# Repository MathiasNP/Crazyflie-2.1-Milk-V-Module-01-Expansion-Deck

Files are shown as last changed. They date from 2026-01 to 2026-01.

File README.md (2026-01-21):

# BT-MV Duo 01 Deck
*A Crazyflie 2.1 expansion deck that brings a Milk-V Duo Module 01 into the nano-UAV world — with hooks for SD/MMC, USB, and a camera.*

> **Status (Rev-A):** boots over UART and power is solid.  
> **Blockers:** SD/MMC and USB are not working yet, which prevents full end-to-end camera validation.

---

## What this project is
This repository contains the hardware design for a Crazyflie 2.1 deck integrating a Milk-V Duo Module 01 (dual-core SoM) to enable on-board compute beyond the stock platform. The aim is a lightweight, compact board that can be manufactured, assembled, and iterated on like any other Crazyflie expansion deck.

---

## Highlights
- Crazyflie deck form factor (mechanically compatible)
- Milk-V Duo Module 01 integration
- Power path designed for both Crazyflie supply (VCOM) and external USB 5 V (VBUS) with automatic switchover
- Interfaces on the board (intended): microSD (SD/MMC), USB 2.0, OV5647-style camera connector, UART debug

---

## What works (verified on Rev-A)
### ✅ Power & regulation
- 3.3 V rail is stable across expected input conditions
- VBUS/VCOM switchover behaves as intended (no brown-out observed during switching)

### ✅ Boot & console
- RISC-V boot path reachable via UART
- U-Boot prompt available and interactive

---

## What does *not* work yet (known issues)
### ❌ SD/MMC (microSD)
Symptoms:
- SDHCI initialisation repeatedly times out
- Environment load from FAT fails; boot falls back to defaults

Most likely causes (current hypotheses):
- Signal integrity / timing margin issues on CMD/CLK/DAT lines
- Protection / filtering choice on the SD bus introducing too much series impedance

### ❌ USB (device not recognised)
Symptoms:
- VBUS present (board powers), but host does not enumerate the device
- Removing protection components on D+/D− did not resolve enumeration

Most likely causes (current hypotheses):
- Attach signalling / CC configuration (if USB-C path is involved)
- D+/D− routing/impedance/return path issues

### ⚠️ Camera
- Camera rails exist and basic clock presence was observed on Rev-A,
  but full camera bring-up is blocked until a reliable flashing / data path exists
  (SD and/or USB need to work first).

---

## Repository structure
```text
BT-MV Duo 01 Deck/
  BT-MV Duo 01 Deck.kicad_pcb            # PCB layout
  BT-MV Duo 01 Deck.kicad_prl            # Local project settings
  BT-MV Duo 01 Deck.kicad_pro            # KiCad project file

  MV Duo 01 Deck Schematics/             # Hierarchical schematics
    BT-MV Duo 01 Deck.kicad_sch          # Top-level schematic
    BT-Power_CFexp.kicad_sch             # Power + Crazyflie expansion interface
    BT-SDcard.kicad_sch                  # microSD (SD/MMC)
    BT-USB_UART.kicad_sch                # USB + UART debug
    BT-CameraOV.kicad_sch                # Camera connector + signals
    BT-MV_DM01.kicad_sch                 # Duo Module integration (pins/straps)
    BT-Others.kicad_sch                  # LEDs, buttons, misc

  BT-MVD01 libraries/                    # Custom KiCad libraries
    Symbols and Footprints/
    3D Models/
    BT-Milk V Duo S.pretty/              # Footprint library

  BT-MV Duo 01 Deck.csv                  # BOM
  BT-MV Duo 01 Deck.kicad_dru            # Design rules

  Related Work/
    CF Proto Exp/                        # Bitcraze deck template/docs
    Milk Module schematics/              # Module + EVB references
    Camera OV5674/                       # Camera reference material (may include mixed sensor notes)

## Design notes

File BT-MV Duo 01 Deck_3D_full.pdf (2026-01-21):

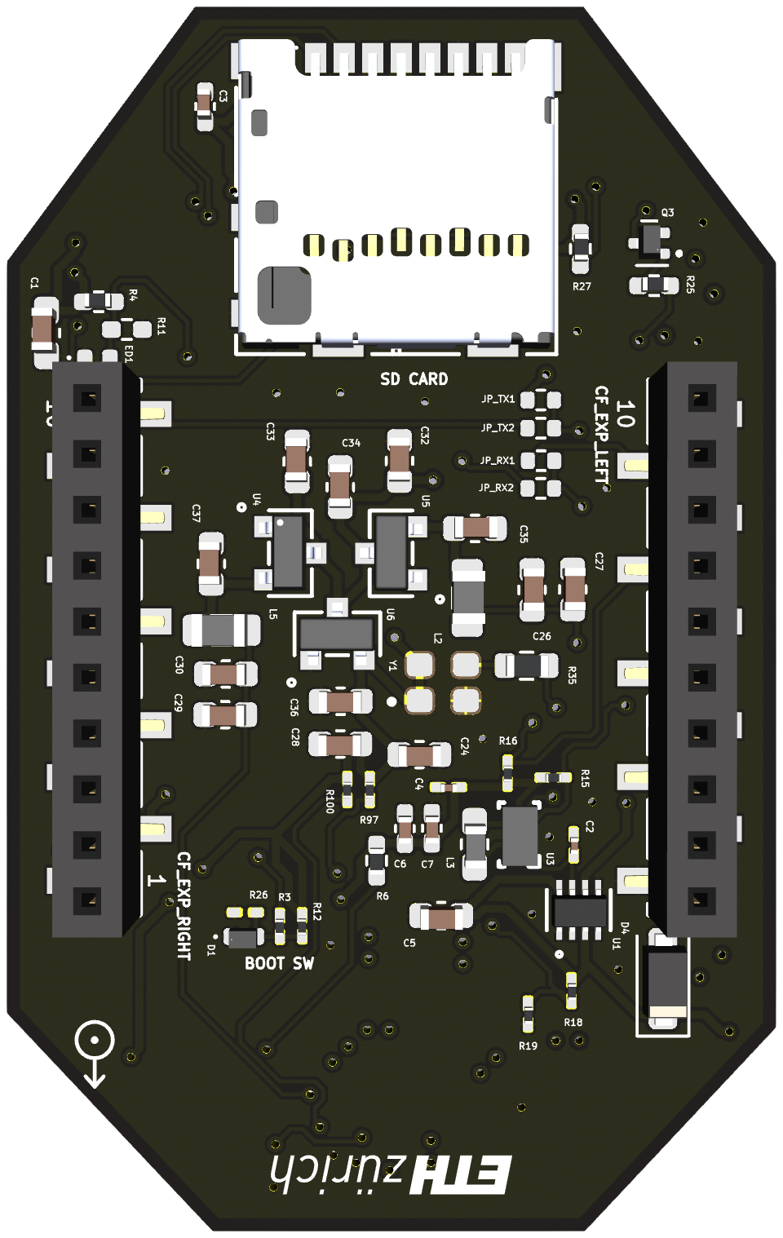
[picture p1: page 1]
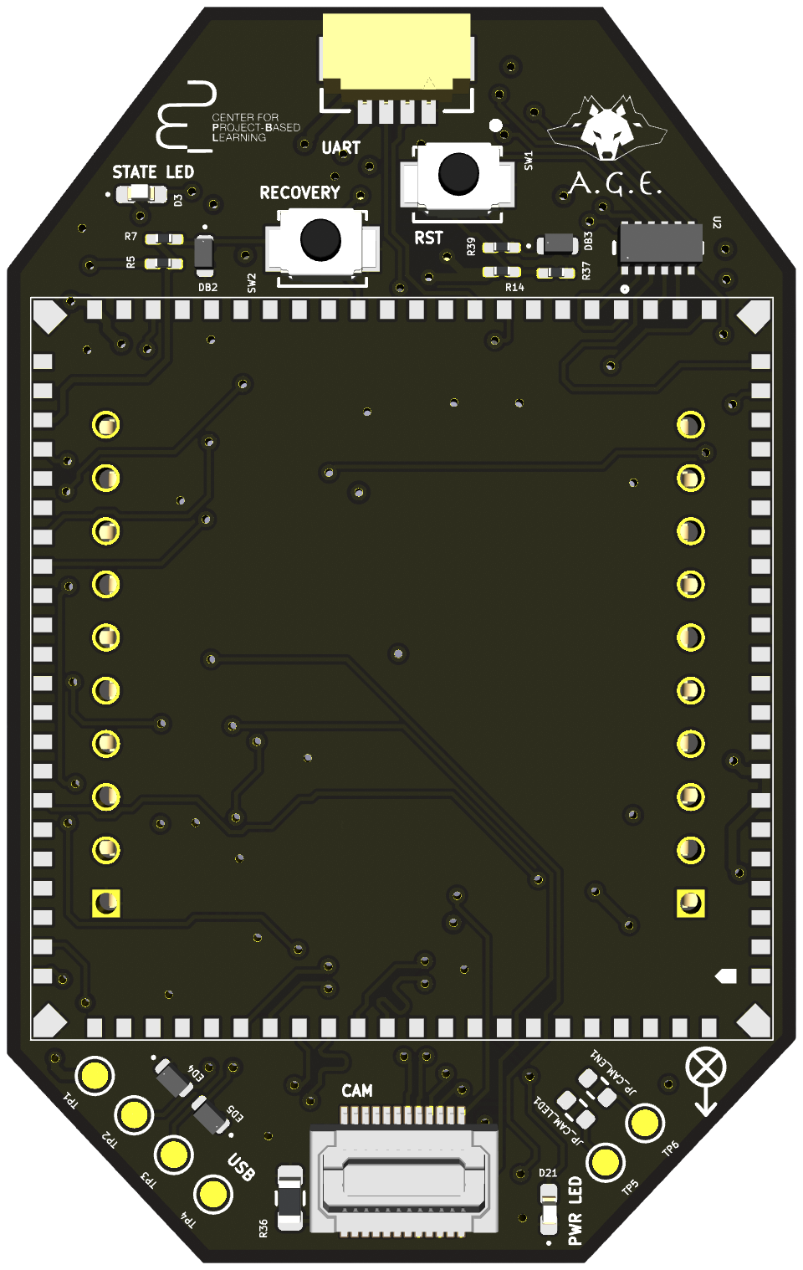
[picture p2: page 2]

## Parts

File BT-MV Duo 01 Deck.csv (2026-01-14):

Reference | Qty | Value | DNP | Exclude from BOM | Exclude from Board | Footprint | Datasheet
C1 | 1 | 10uF |  |  |  | Capacitor_SMD:C_0603_1608Metric_Pad1.08x0.95mm_HandSolder | CM05X5R106M10AH
C2 | 1 | 10uF |  |  |  | Capacitor_SMD:C_0201_0603Metric_Pad0.64x0.40mm_HandSolder | CM05X5R106M10AH
C3 | 1 | 100nF |  |  |  | Capacitor_SMD:C_0402_1005Metric_Pad0.74x0.62mm_HandSolder | GRM155R61A104KA01J
C4 | 1 | 100nF |  |  |  | Capacitor_SMD:C_0201_0603Metric_Pad0.64x0.40mm_HandSolder | GRM033R61A104ME15D
C5,C32,C33,C34,C35,C36,C37 | 7 | 1uF |  |  |  | Capacitor_SMD:C_0603_1608Metric | CL10A105KA8NNNC
C6,C7 | 2 | 22uF |  |  |  | Capacitor_SMD:C_0402_1005Metric_Pad0.74x0.62mm_HandSolder | GRM155R60J226ME11D
C24,C27,C28,C30 | 4 | 10nF |  |  |  | Capacitor_SMD:C_0603_1608Metric | GCM188R71H103KA37J
C26,C29 | 2 | 1nF |  |  |  | Capacitor_SMD:C_0603_1608Metric | CC0603KRX7R9BB102
D1,DB2,DB3,ED1,ED4,ED5 | 6 | SP0402B-ULC-01ETG |  |  |  | Diode_SMD:D_0402_1005Metric | SP0402B-ULC-01ETG
D3 | 1 | BLUE HIGH D402 |  |  |  | LED_SMD:LED_0402_1005Metric_Pad0.77x0.64mm_HandSolder | 150040BS73240
D4 | 1 | SMBJ18A |  |  |  | Diode_SMD:D_SOD-123F | SMBJ18A
D21 | 1 | RED HIGH D402 |  |  |  | LED_SMD:LED_0402_1005Metric_Pad0.77x0.64mm_HandSolder | 150040RS73240
J1 | 1 | 1040310811 |  |  |  | BT-Milk V Duo S:104031-0811_MOL | 104031-0811
J2 | 1 | STAMP_HOLE_88P |  |  |  | BT-Milk V Duo S:MilkV_Duo_Module | https://milkv.io/duo-module-01
J6 | 1 | DF52-4S-0.8H21 |  |  |  | BT-Milk V Duo S:CONN4X1_DF52-4S-0.8H21_HIR | https://www.mouser.ch/datasheet/3/731/1/DF52_2832PCF_CL0668_0030_5_00_Catalog_en_DF52_CAT.pdf
JP_CAM_EN1,JP_CAM_LED1,JP_RX1,JP_RX2,JP_TX1,JP_TX2 | 6 | 0R | DNP |  |  | Resistor_SMD:R_0402_1005Metric | RC0402JR-070RP
L2,L5 | 2 | 1.5k |  |  |  | Inductor_SMD:L_0805_2012Metric | BLM21BD152SH1D
L3 | 1 | 0.47uH |  |  |  | Inductor_SMD:L_0201_0603Metric_Pad0.64x0.40mm_HandSolder | LBCNF1608KKTR47MAD
P1 | 1 | CF_EXP_LEFT |  |  |  | BT-Milk V Duo S:CF2-DECK-SMD-HOLES | https://store.bitcraze.io/products/female-deck-connector?utm_source=chatgpt.com
P2 | 1 | CF_EXP_RIGHT |  |  |  | BT-Milk V Duo S:CF2-DECK-SMD-HOLES | https://store.bitcraze.io/products/female-deck-connector?utm_source=chatgpt.com
Q3 | 1 | CJ3134K |  |  |  | Package_TO_SOT_SMD:SOT-723 | CJ3134K / NTK3134NT1G
R3,R7,R39 | 3 | 100R 5% |  |  |  | Resistor_SMD:R_0201_0603Metric_Pad0.64x0.40mm_HandSolder | AC0201JR-07100RL
R4 | 1 | 100k(NC) |  |  |  | Resistor_SMD:R_0402_1005Metric_Pad0.72x0.64mm_HandSolder | RC0402FR-07100KL
R5,R12 | 2 | 10k 1% |  |  |  | Resistor_SMD:R_0201_0603Metric_Pad0.64x0.40mm_HandSolder | AC0201FR-0710KL
R6 | 1 | 510R 5% |  |  |  | Resistor_SMD:R_0402_1005Metric_Pad0.72x0.64mm_HandSolder | RC0402JR-07510RL
R11 | 1 | 100k(NC) | DNP |  |  | Resistor_SMD:R_0402_1005Metric_Pad0.72x0.64mm_HandSolder | RC0402FR-07100KL
R14,R15,R16,R97,R100 | 5 | 4.7k |  |  |  | Resistor_SMD:R_0201_0603Metric_Pad0.64x0.40mm_HandSolder | AC0201JR-074K7L
R18 | 1 | 150k |  |  |  | Resistor_SMD:R_0201_0603Metric_Pad0.64x0.40mm_HandSolder | AA0201FR-07150KL
R19 | 1 | 100k |  |  |  | Resistor_SMD:R_0201_0603Metric_Pad0.64x0.40mm_HandSolder | AA0201FR-07100KL
R25,R27 | 2 | 1k |  |  |  | Resistor_SMD:R_0402_1005Metric_Pad0.72x0.64mm_HandSolder | RC0402JR-071KL
R26 | 1 | 10k 1% | DNP |  |  | Resistor_SMD:R_0201_0603Metric_Pad0.64x0.40mm_HandSolder | AC0201FR-0710KL
R35 | 1 | 100R |  |  |  | Resistor_SMD:R_0603_1608Metric | RC0603FR-07100RL
R36 | 1 | 10k |  |  |  | Resistor_SMD:R_0603_1608Metric | RC0603FR-0710KL
R37 | 1 | 3.3k |  |  |  | Resistor_SMD:R_0201_0603Metric_Pad0.64x0.40mm_HandSolder | AC0201JR-073K3L
SW1,SW2 | 2 | B3U-1000P |  |  |  | Button_Switch_SMD:SW_SPST_B3U-1000P | B3U-1000P
TP1 | 1 | VBUS |  |  |  | TestPoint:TestPoint_Pad_D1.0mm | ~
TP2 | 1 | D- |  |  |  | TestPoint:TestPoint_Pad_D1.0mm | ~
TP3 | 1 | D+ |  |  |  | TestPoint:TestPoint_Pad_D1.0mm | ~
TP4 | 1 | GND |  |  |  | TestPoint:TestPoint_Pad_D1.0mm | ~
TP5,TP6 | 2 | TestPoint |  |  |  | TestPoint:TestPoint_Pad_D1.0mm | ~
U1 | 1 | LM66200DRLR |  |  |  | BT-Milk V Duo S:SOT-5X3_DRL_TEX | LM66200DRLR
U2 | 1 | EMIF06-1005MX12Y |  |  |  | BT-Milk V Duo S:SON_5MX12Y_STM | EMIF06-1005MX12Y
U3 | 1 | TPS63810YFFR |  |  |  | BT-Milk V Duo S:YFF0015AHAN | TPS63810YFFR
U4 | 1 | AP7313-15SRG-7 |  |  |  | BT-Milk V Duo S:SOT-23_DIO | AP7313-15SRG-7
U5 | 1 | AP2127N-2.8TRG1 |  |  |  | BT-Milk V Duo S:SOT-23_DIO | AP2127N-2.8TRG1
U6 | 1 | AP2127N-1.8TRG1 |  |  |  | BT-Milk V Duo S:SOT-23_DIO | AP2127N-1.8TRG1
U7 | 1 | DF30FC-24DS-0.4V(81) |  |  |  | BT-Milk V Duo S:DF30FC-24DS | DF30FC-24DS-0.4V(81)
Y1 | 1 | SG-210STF_25.0000MY |  |  |  | BT-Milk V Duo S:OSCCC250X200X90 | SG-210STF 25.0000MY

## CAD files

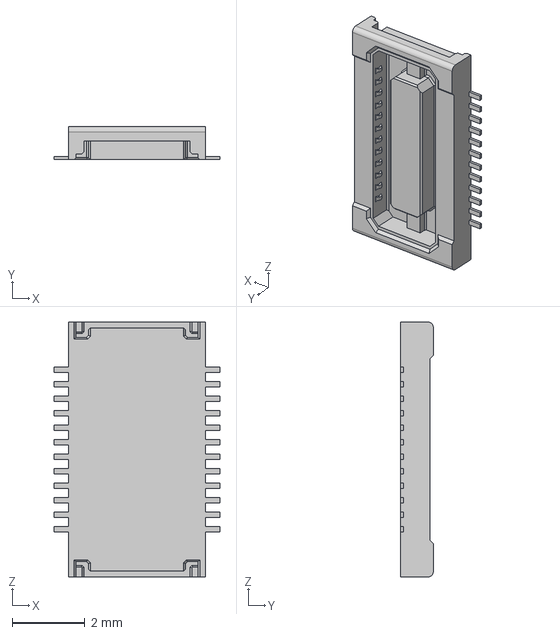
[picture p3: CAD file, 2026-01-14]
BT-MVD01 libraries/Symbols and Footprints/DF30FC-24DS-0.4V_82_/DF30FC-24DS-0.4V_82_.step
4.56 x 0.9 x 7.02 mm

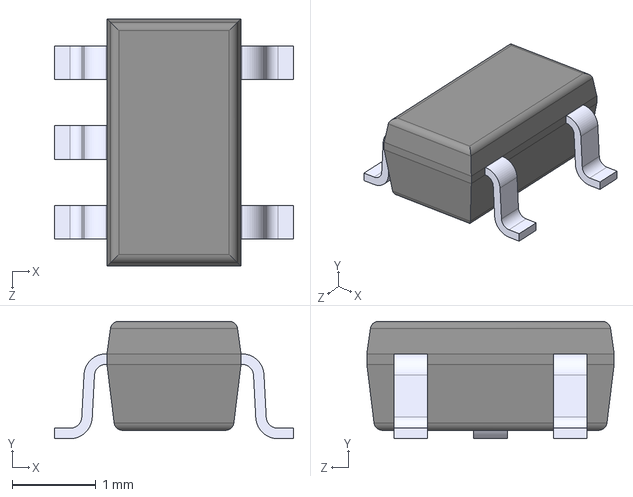
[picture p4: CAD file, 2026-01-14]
BT-MVD01 libraries/Symbols and Footprints/SY6280AAC/SY6280AAC.step
2.85 x 1.40 x 2.95 mm

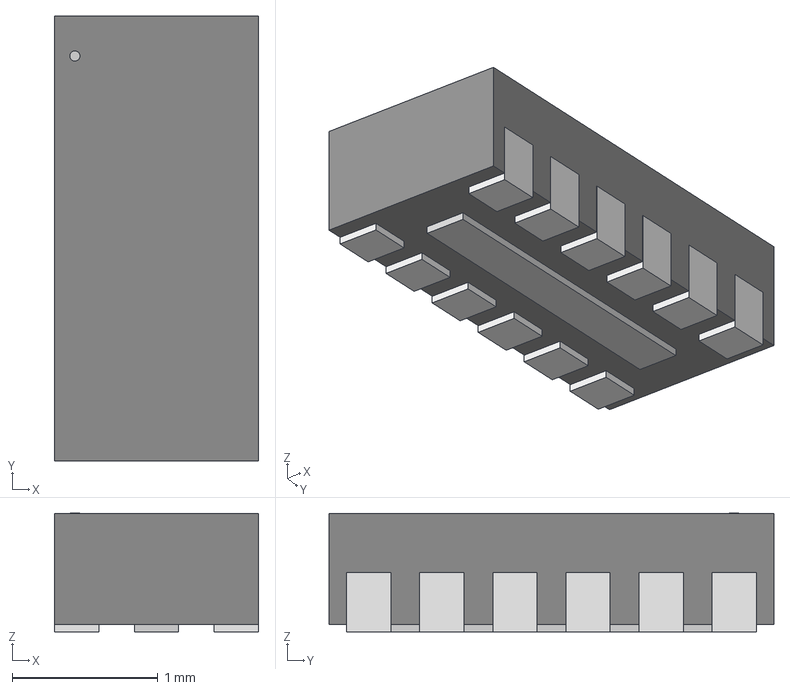
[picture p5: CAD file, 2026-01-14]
BT-MVD01 libraries/Symbols and Footprints/ul_EMIF06-1005MX12Y-2/SON_5MX12Y_STM.step
1.40 x 3.05 x 0.815 mm

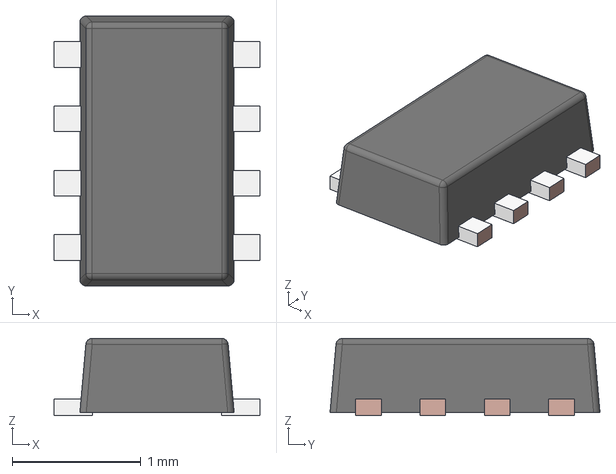
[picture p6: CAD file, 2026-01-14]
BT-MVD01 libraries/Symbols and Footprints/ul_LM66200DRLR-2/DRL0008A.stp
1.60 x 2.10 x 0.6 mm
FRAME-DRL0008A
BODY-SOT

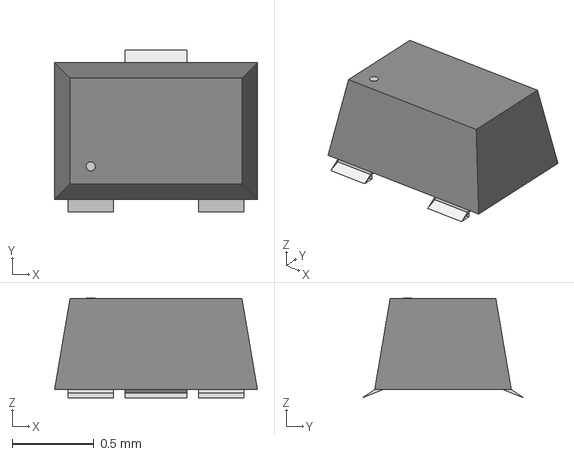
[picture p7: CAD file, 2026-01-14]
BT-MVD01 libraries/Symbols and Footprints/ul_NTK3134NT1G/SOT_34NT1G_ONS.step
1.24 x 0.99 x 0.612 mm

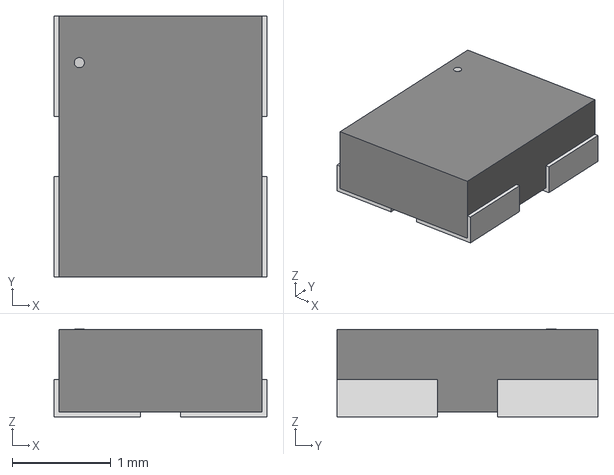
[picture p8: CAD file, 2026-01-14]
BT-MVD01 libraries/Symbols and Footprints/ul_SG-210STF-24-0000ML0/SG-210STF_EPS.step
2.16 x 2.64 x 0.892 mm

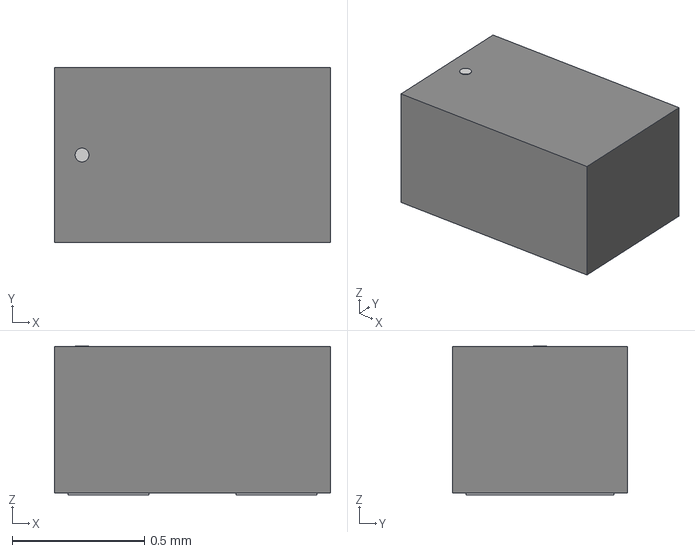
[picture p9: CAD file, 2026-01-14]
BT-MVD01 libraries/Symbols and Footprints/ul_SP0402B-ULC-01ETG/SP0402_LTF.step
1.04 x 0.66 x 0.561 mm

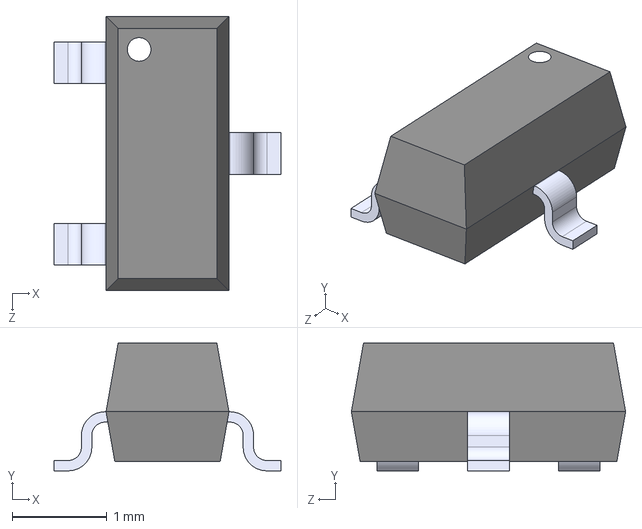
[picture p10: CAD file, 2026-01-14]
BT-MVD01 libraries/3D Models/AP7313-15SRG-7.STEP
2.40 x 1.35 x 2.90 mm

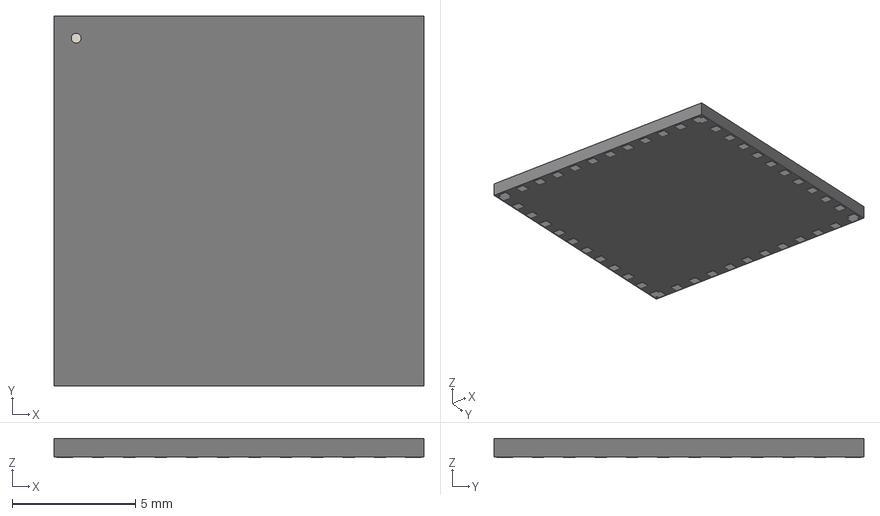
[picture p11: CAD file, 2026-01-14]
BT-MVD01 libraries/3D Models/Linear_LGA-133_15.0x15.0_Layout12x12_P1.27mm.step
15.0 x 15.0 x 0.78 mm

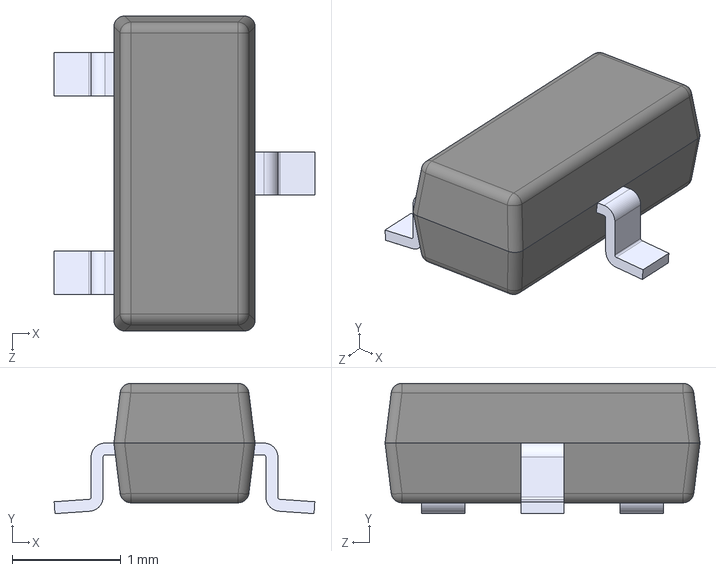
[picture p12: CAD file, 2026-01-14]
BT-MVD01 libraries/3D Models/AP2127N-2.8TRG1.STEP
2.40 x 1.20 x 2.90 mm

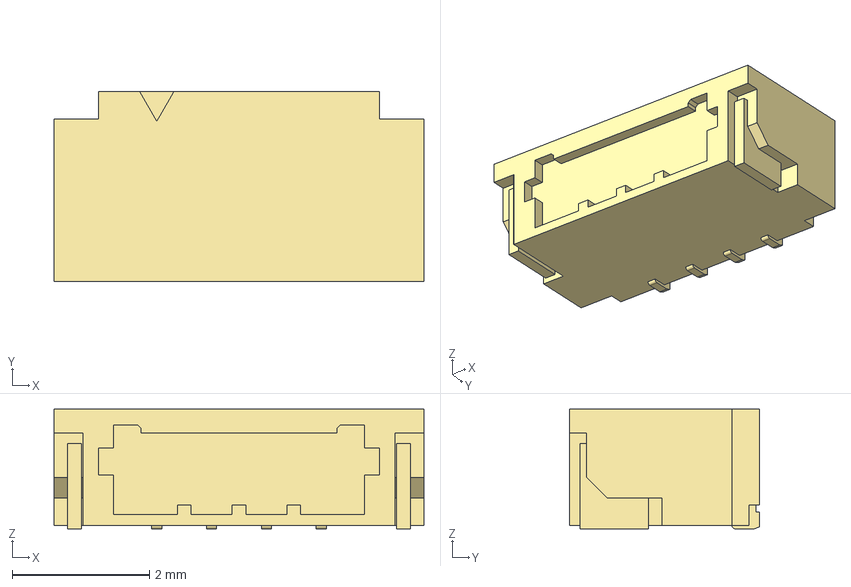
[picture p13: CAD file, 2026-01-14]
BT-MVD01 libraries/3D Models/DF52-4S-0.8H-21---3DModel-STEP-1.STEP
5.40 x 2.77 x 1.75 mm

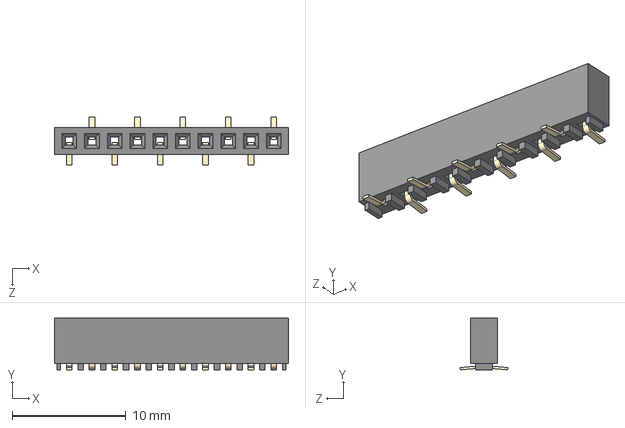
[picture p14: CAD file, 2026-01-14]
BT-MVD01 libraries/3D Models/BF090-10-A-1-N-D--3DModel-STEP-56544.STEP
20.6 x 4.55 x 4.20 mm
BF090-xxxx body_10
pin^BF090-xxxx x 5

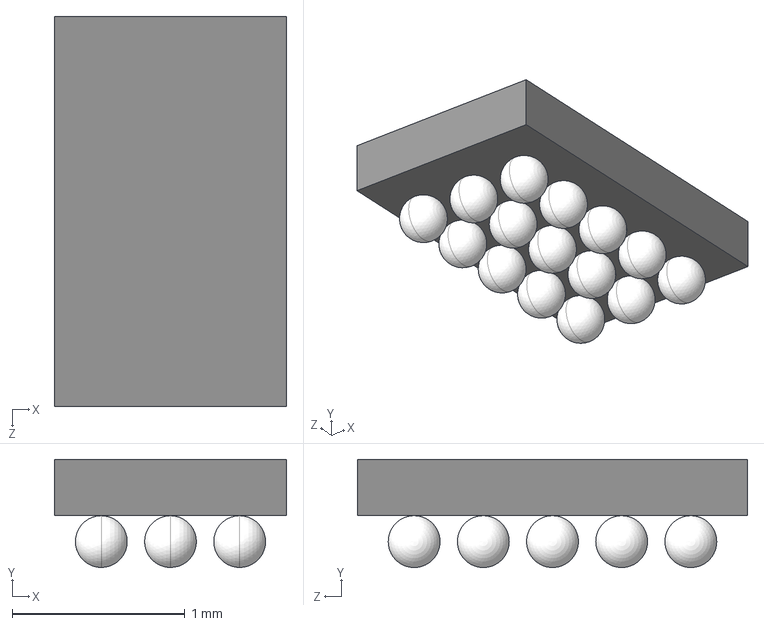
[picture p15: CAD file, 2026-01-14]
BT-MVD01 libraries/3D Models/TPS63805YFFR--3DModel-STEP-56544.STEP
1.34 x 0.625 x 2.25 mm

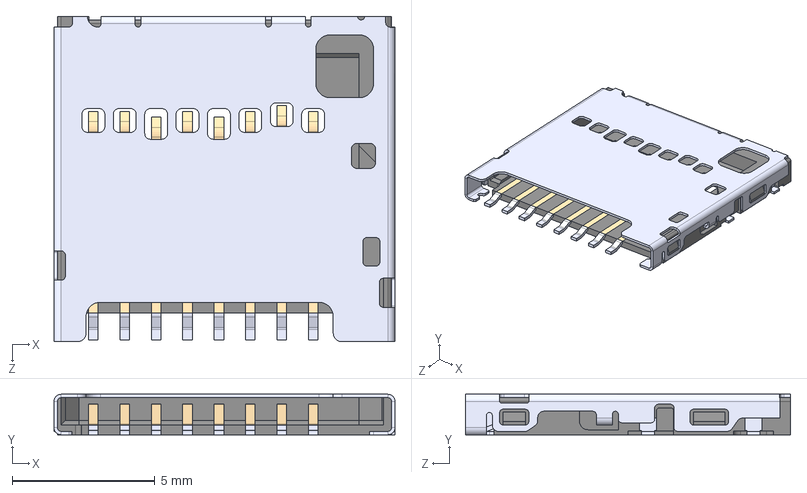
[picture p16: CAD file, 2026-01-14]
BT-MVD01 libraries/3D Models/104031-0811--3DModel-STEP-269445.STEP
12.0 x 1.42 x 11.4 mm

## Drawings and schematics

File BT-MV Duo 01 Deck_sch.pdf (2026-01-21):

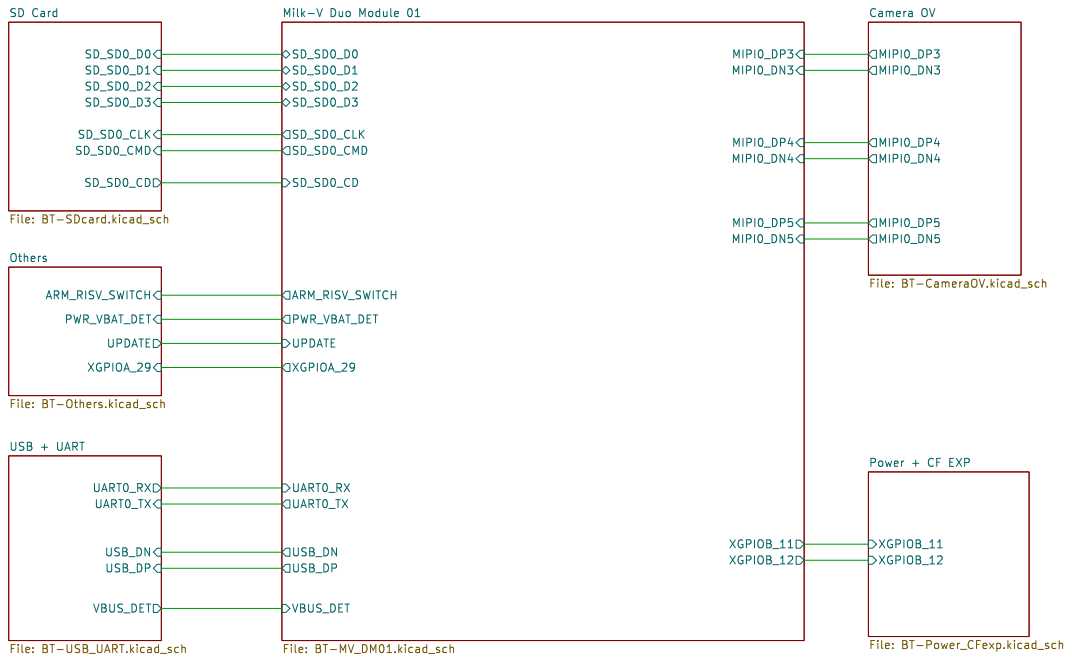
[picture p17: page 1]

SD Card File: BT-SDcard.kicad_sch ARM_RISV_SWITCH
XGPIOA_29 Others File: BT-Others.kicad_sch UART0_RX UART0_TX USB_DN

File: BT-Power_CFexp.kicad_sch MIPI0_DN4 MIPI0_DP3 MIPI0_DP5 MIPI0_DN3 MIPI0_DN5 MIPI0_DP4 Camera OV

Id: 1/7 Title: BT-MV Duo 01 Deck

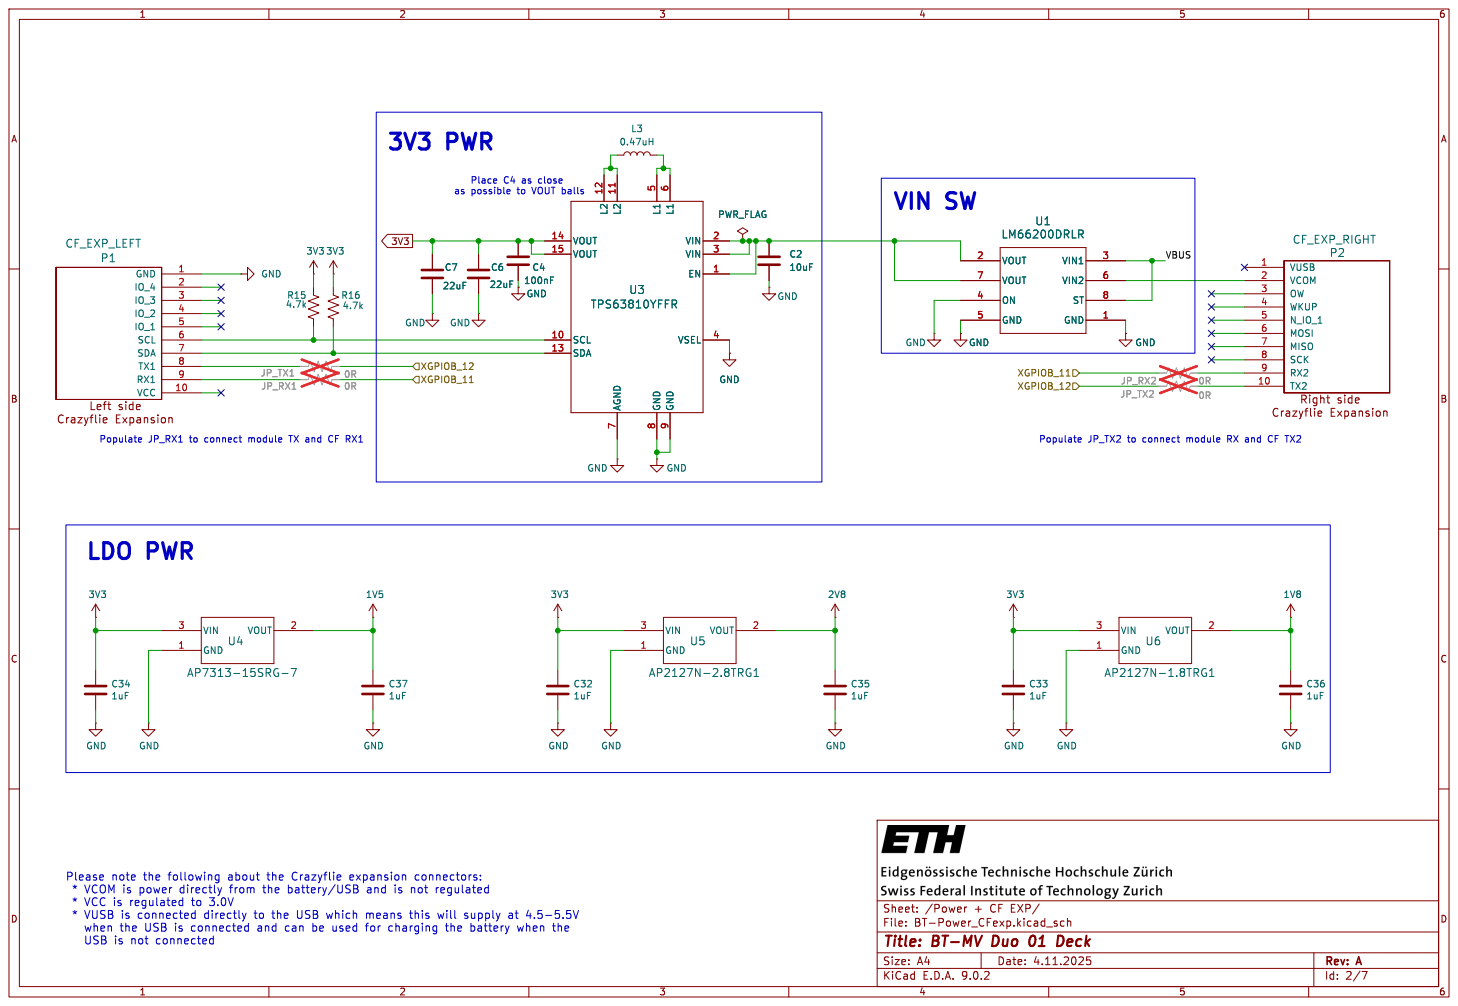
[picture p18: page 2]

7 VOUT 14 VOUT 15 SCL 10 SDA 13 L1

Id: 2/7 Title: BT-MV Duo 01 Deck

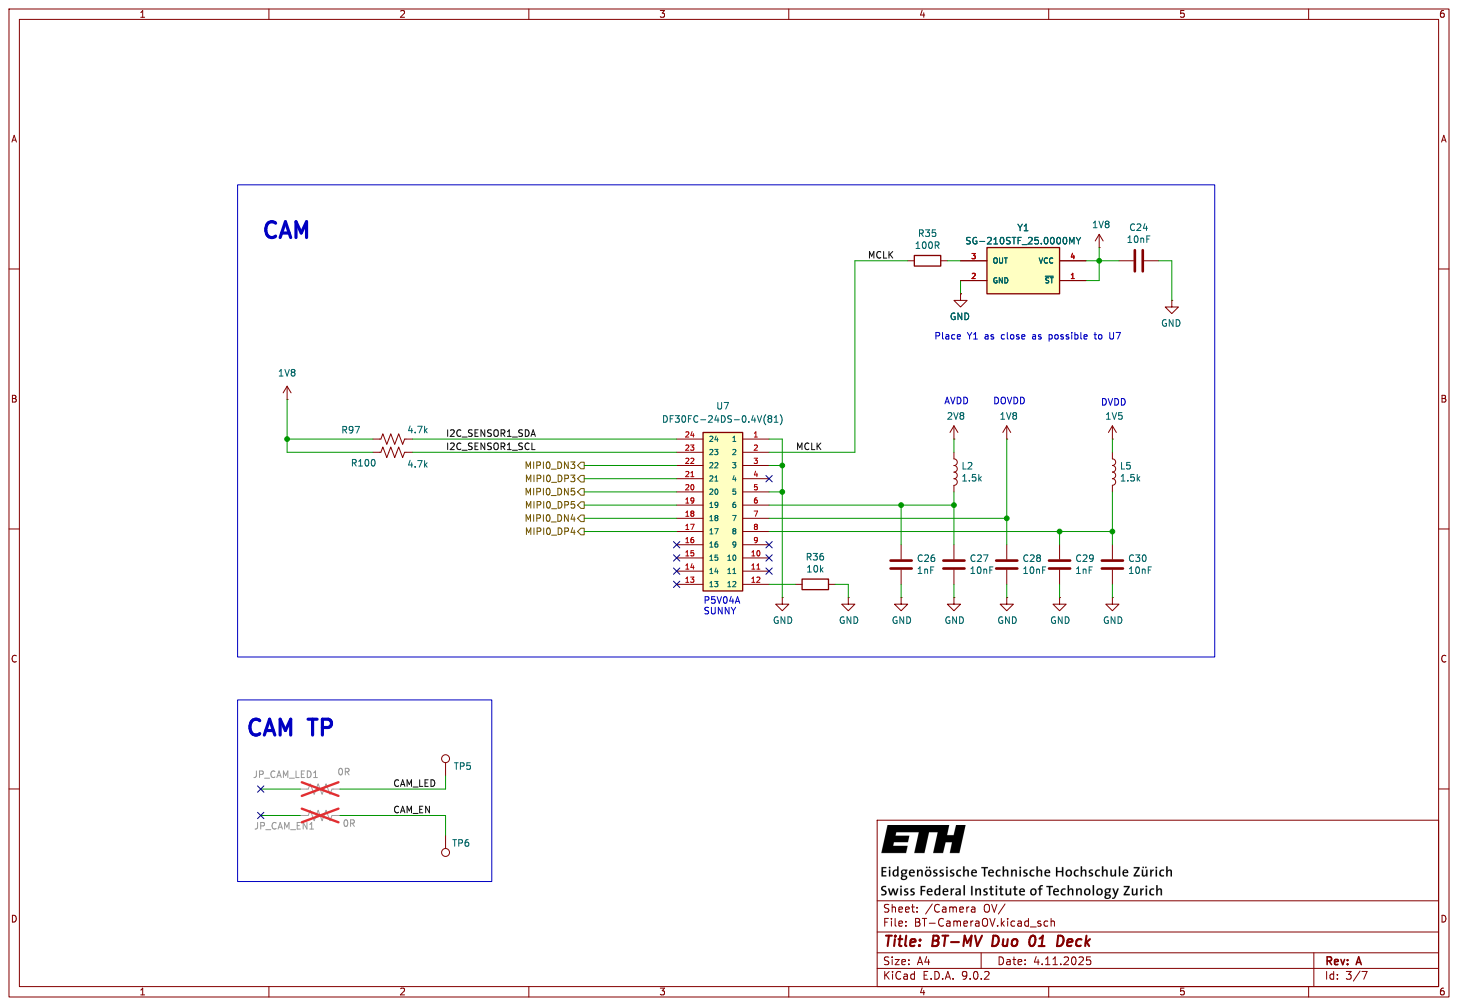
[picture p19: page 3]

Id: 3/7 Title: BT-MV Duo 01 Deck

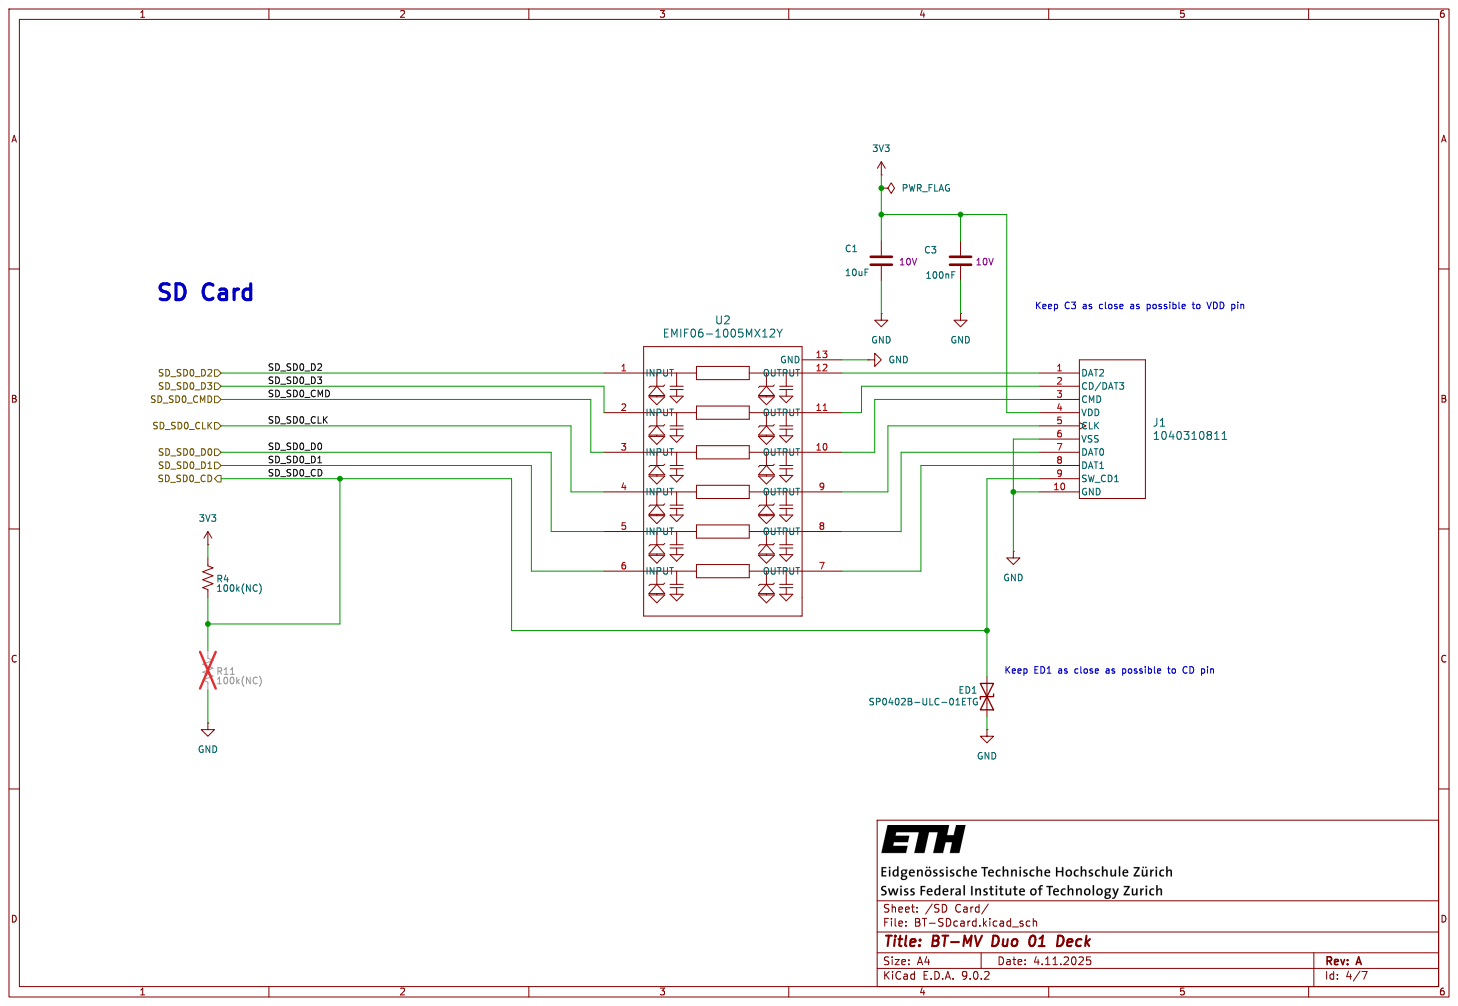
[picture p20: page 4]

Id: 4/7 Title: BT-MV Duo 01 Deck

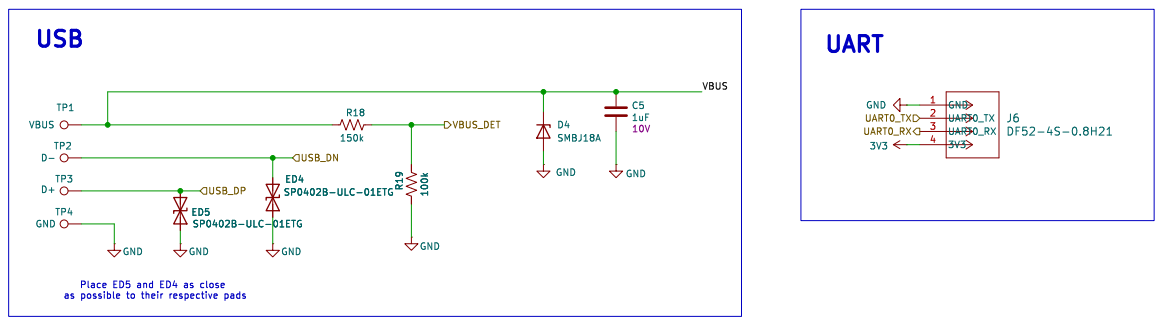
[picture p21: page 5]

Place ED5 and ED4 as close

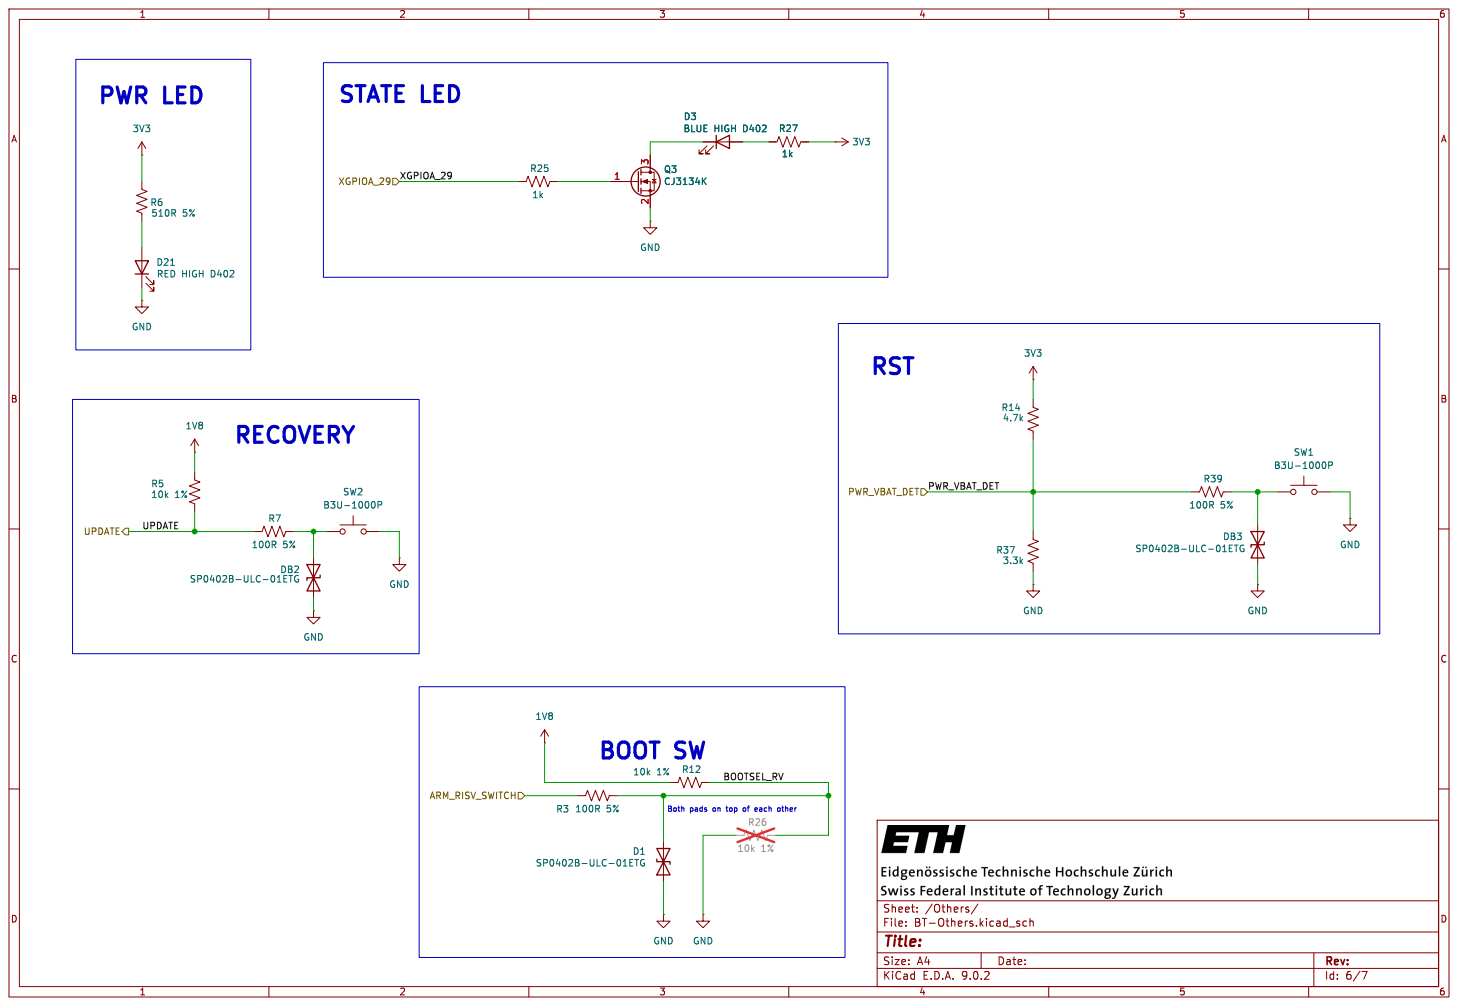
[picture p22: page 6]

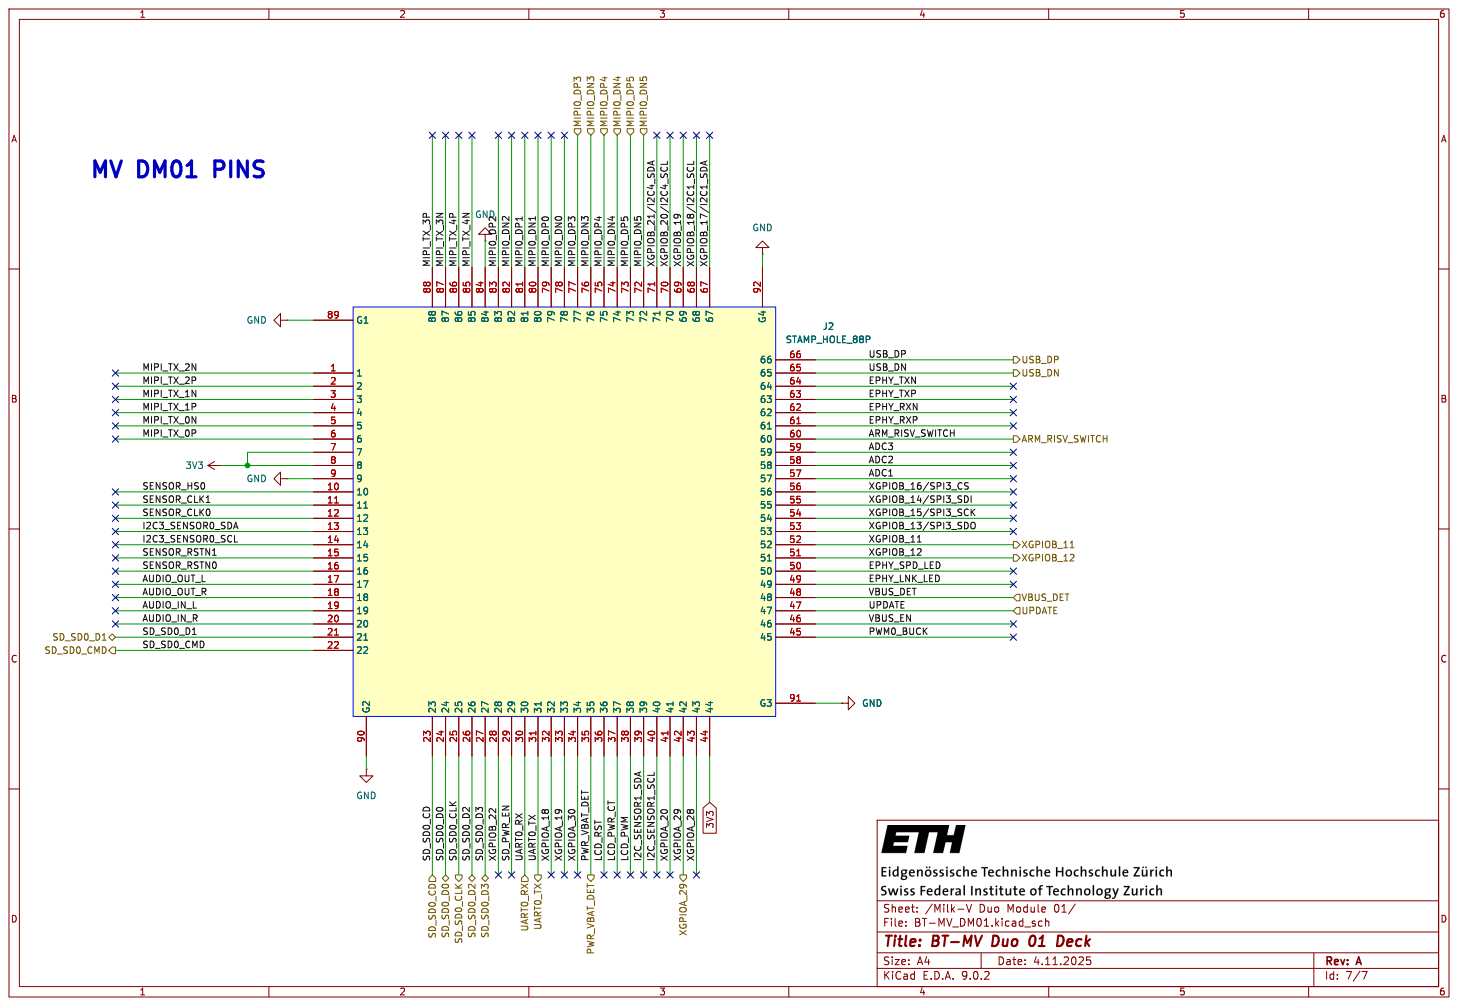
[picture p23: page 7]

Id: 7/7 Title: BT-MV Duo 01 Deck

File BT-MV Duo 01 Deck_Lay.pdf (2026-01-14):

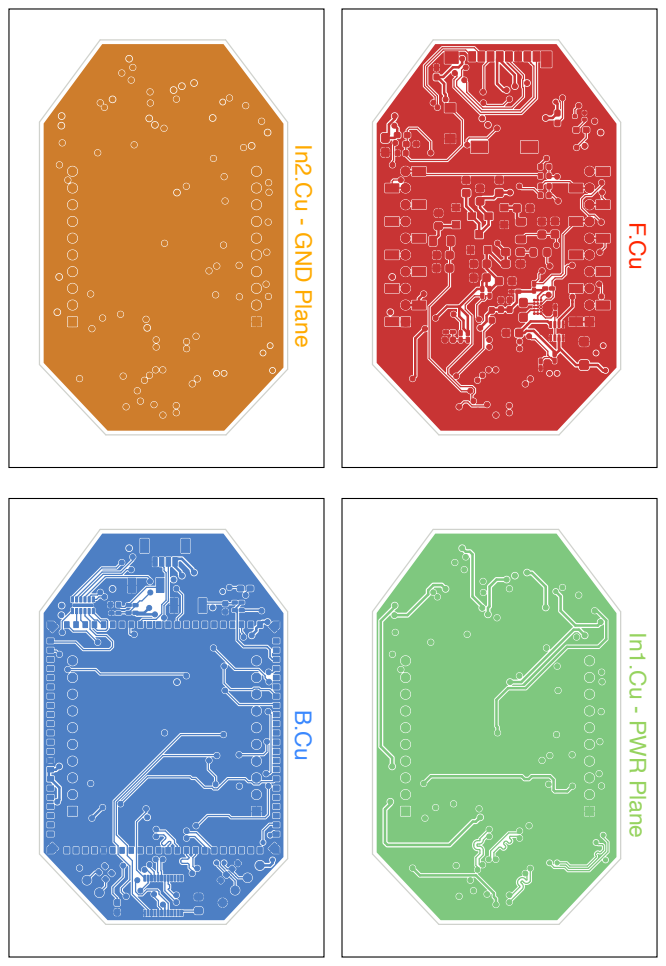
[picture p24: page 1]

In2.Cu - GND Plane

In1.Cu - PWR Plane

# SD CARD

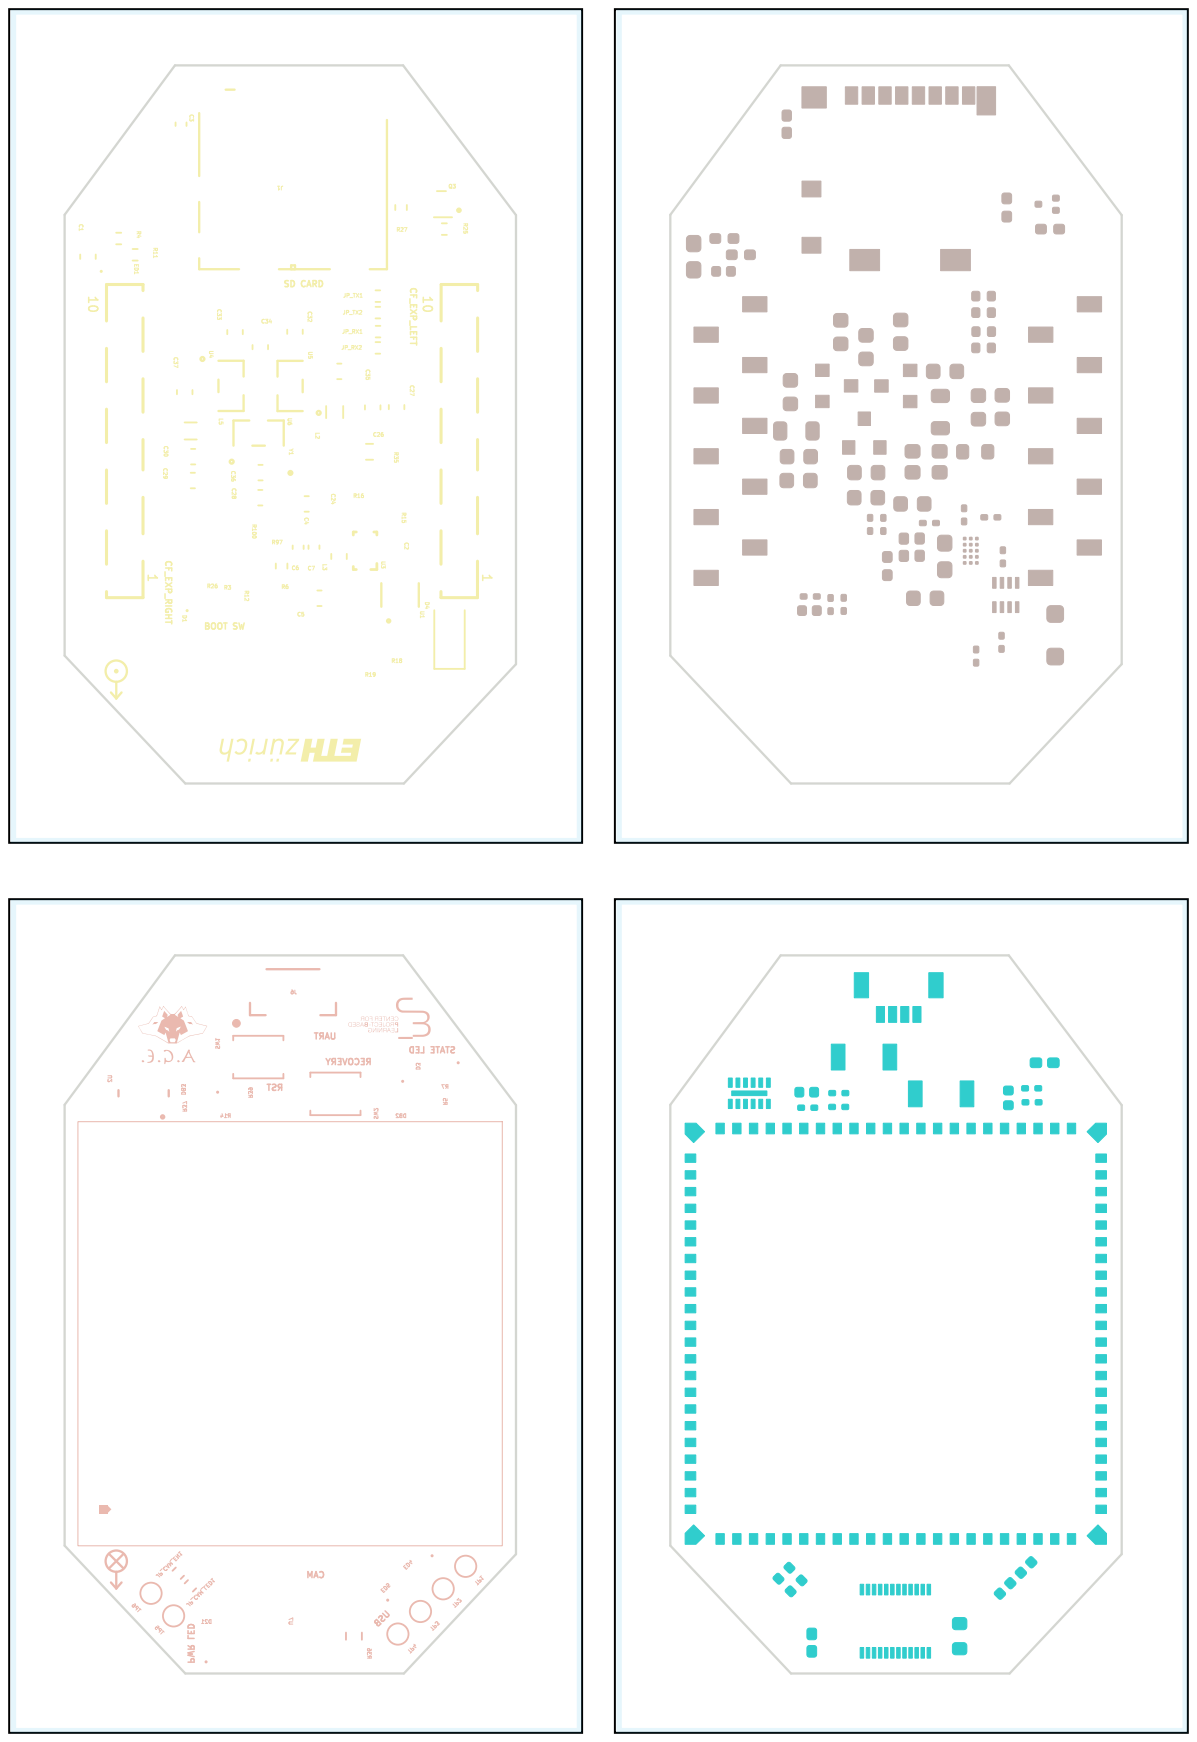
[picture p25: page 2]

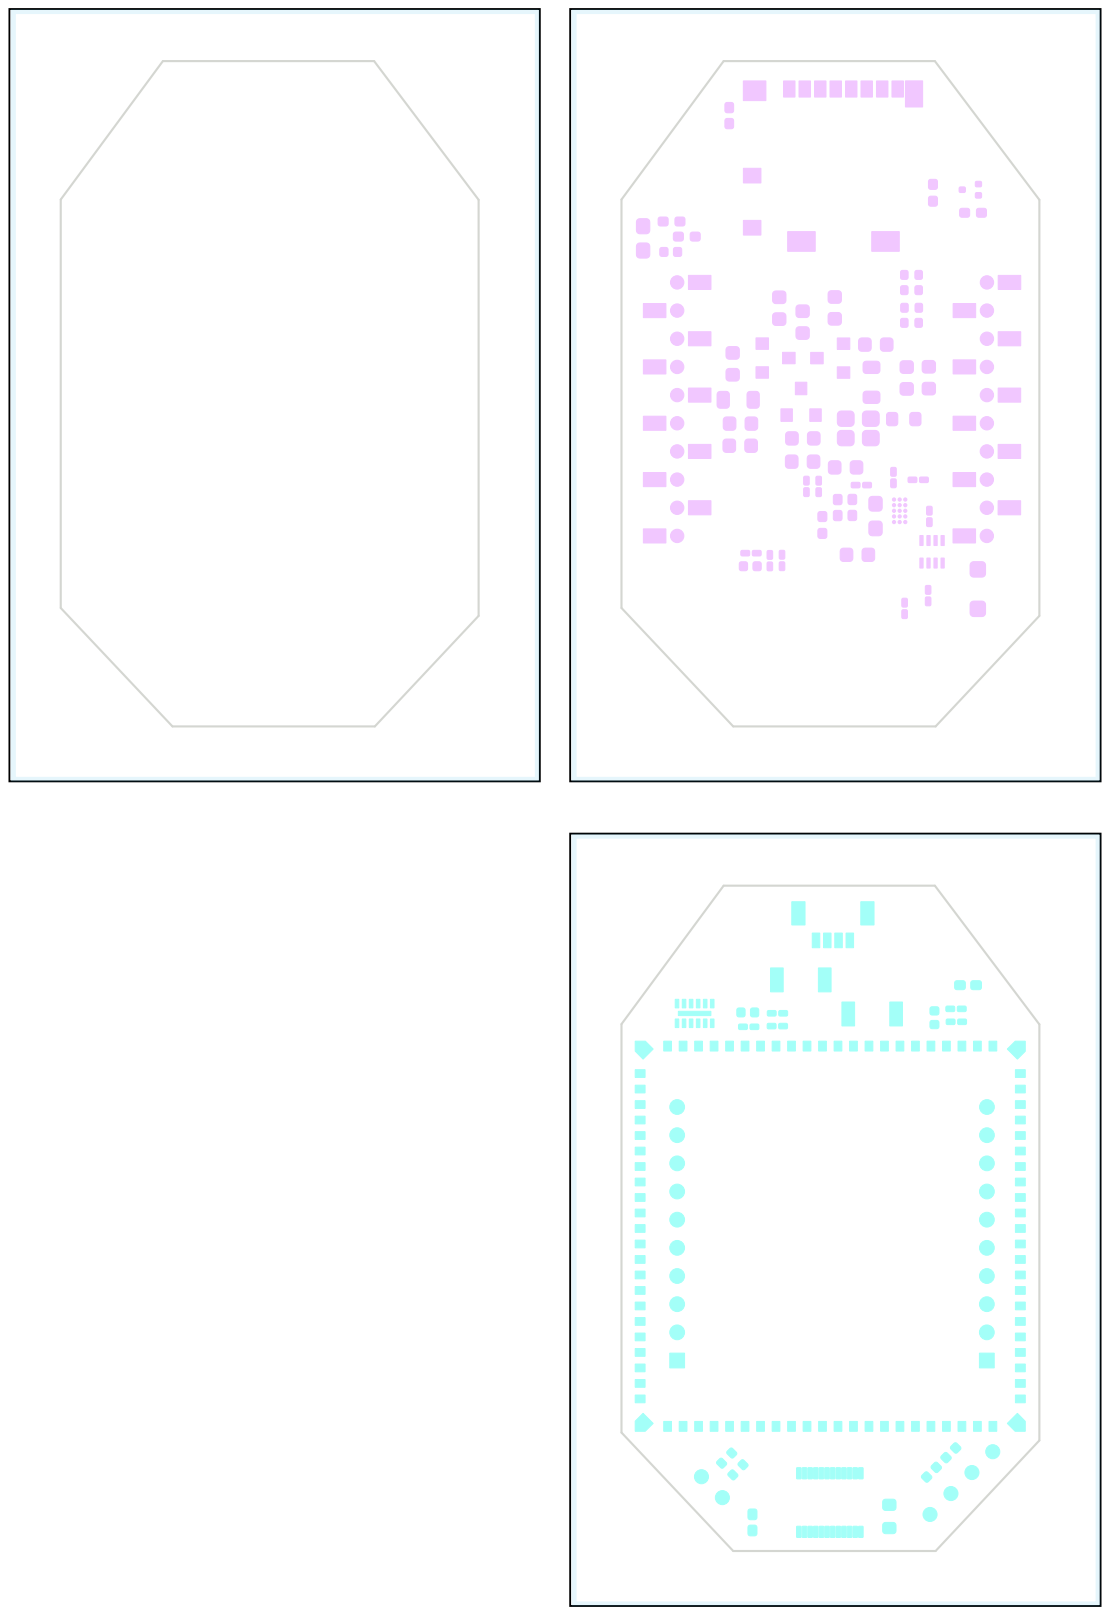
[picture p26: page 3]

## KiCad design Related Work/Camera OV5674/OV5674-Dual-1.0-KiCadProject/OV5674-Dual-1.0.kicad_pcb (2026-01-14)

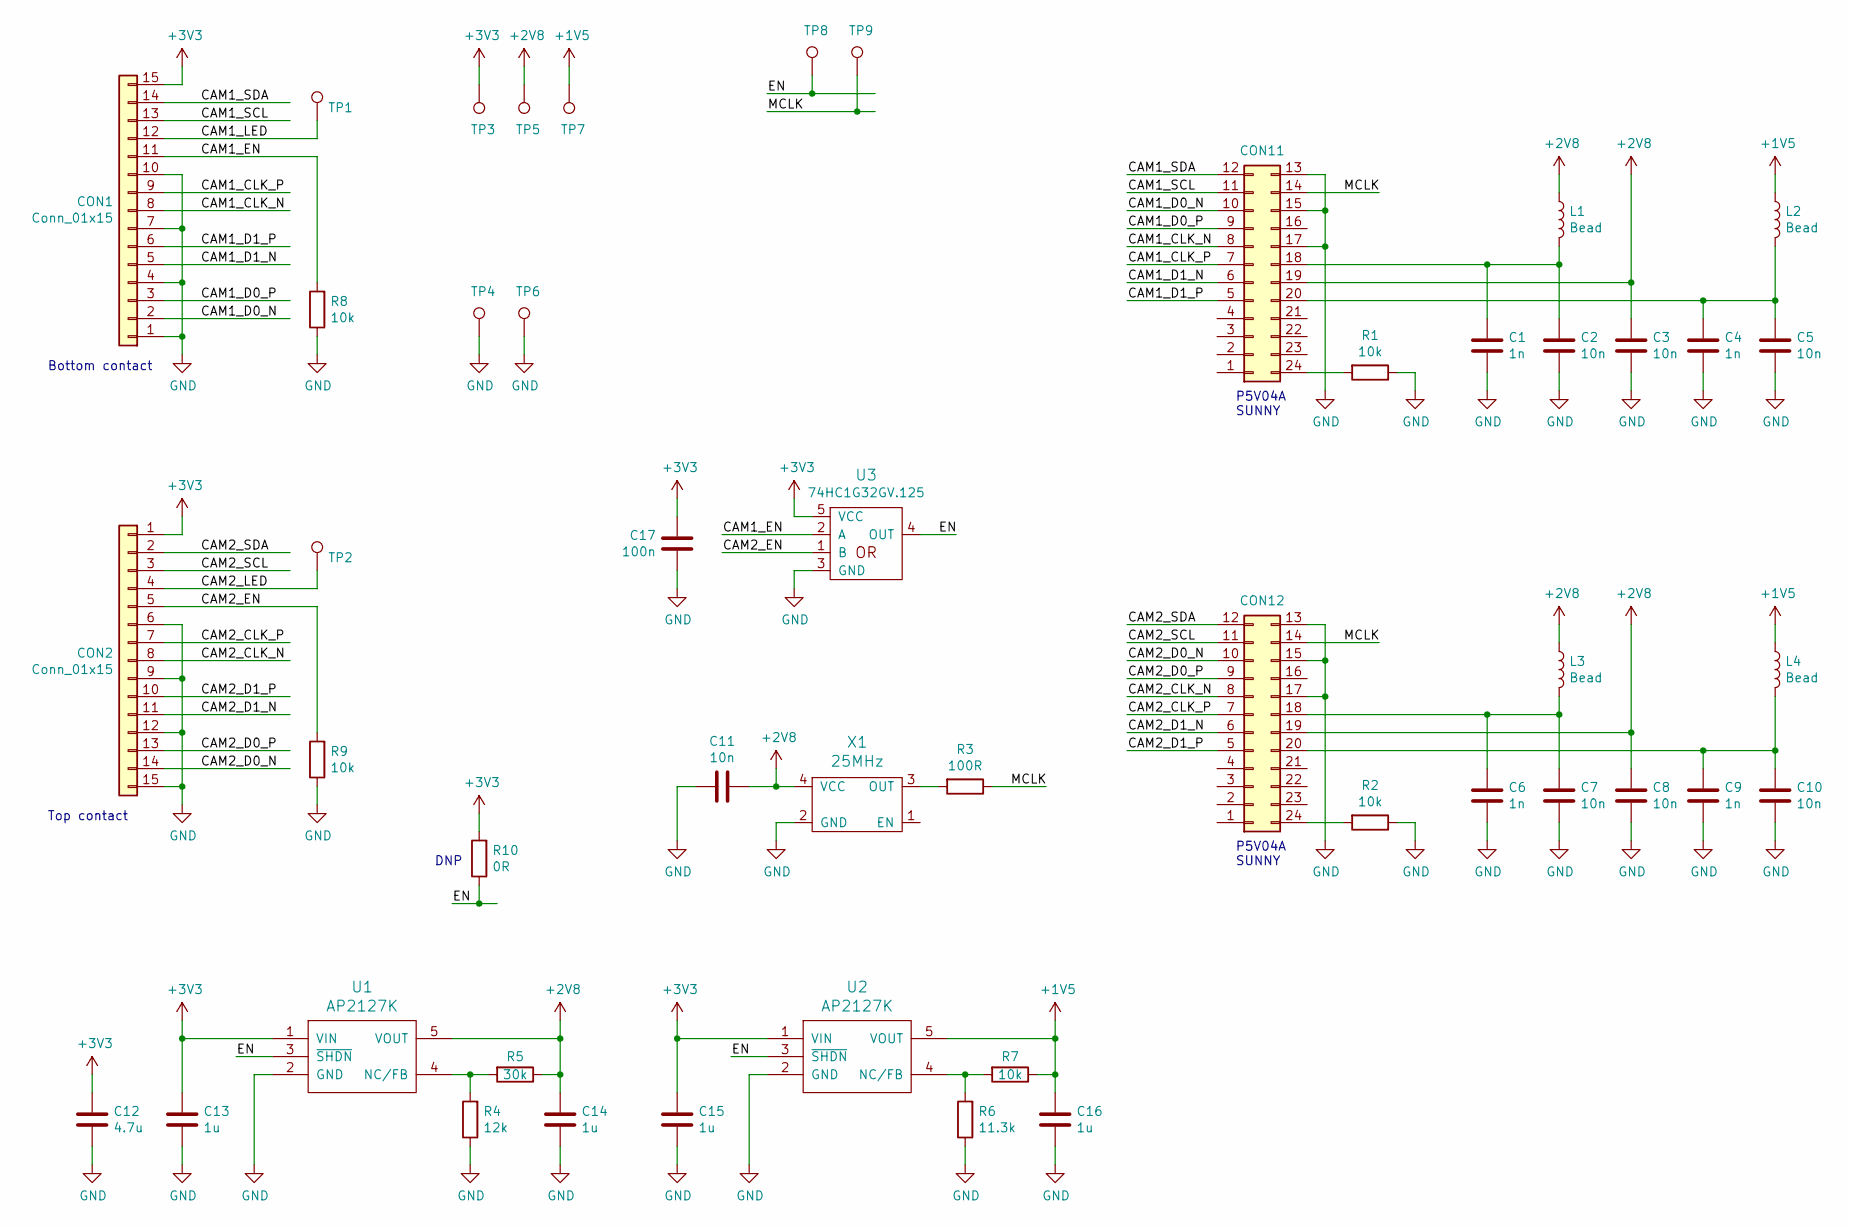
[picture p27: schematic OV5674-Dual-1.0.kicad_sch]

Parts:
C1, C4, C6, C9: 1n; C_0603_1608Metric
C2, C3, C5, C7, C8, C10, C11: 10n; C_0603_1608Metric
C12: 4.7u; C_0805_2012Metric
C13, C14, C15, C16: 1u; C_0603_1608Metric
C17: 100n; C_0603_1608Metric
CON1, CON2: Conn_01x15; TE_1-84952-5_1x15-1MP_P1.0mm_Horizontal
CON11, CON12: Conn_02x12_Counter_Clockwise; DF30FC-24DP-0.4V
L1, L2, L3, L4: Bead; L_0805_2012Metric
R1, R2, R7, R8, R9: 10k; R_0603_1608Metric
R3: 100R; R_0603_1608Metric
R4: 12k; R_0603_1608Metric
R5: 30k; R_0603_1608Metric
R6: 11.3k; R_0603_1608Metric
R10: 0R; R_0603_1608Metric
TP1, TP2, TP3, TP4: TestPoint; TestPoint_Pad_D1.5mm
TP5, TP6, TP7, TP8, TP9: TestPoint; TestPoint_Pad_D1.0mm
U1, U2: AP2127K; SOT-23-5
U3: 74xx1G32; SC-74A
X1: 25MHz; CFPS-39

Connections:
+1V5: C16.1, L2.1, L4.1, R7.1, TP7.1, U2.5 (VOUT)
+2V8: C3.1, C8.1, C11.1, C14.1, CON11.19, CON12.19, L1.1, L3.1, R5.1, TP5.1, U1.5 (VOUT), X1.4 (VCC)
+3V3: C12.1, C13.1, C15.1, C17.1, CON1.15, CON2.1, R10.2, TP3.1, U1.1 (VIN), U2.1 (VIN), U3.5 (VCC)
/CAM1_CLK_N: CON1.8, CON11.8
/CAM1_CLK_P: CON1.9, CON11.7
/CAM1_D0_N: CON1.2, CON11.10
/CAM1_D0_P: CON1.3, CON11.9
/CAM1_D1_N: CON1.5, CON11.6
/CAM1_D1_P: CON1.6, CON11.5
/CAM1_EN: CON1.11, R8.2, U3.2 (A)
/CAM1_LED: CON1.12, TP1.1
/CAM1_SCL: CON1.13, CON11.11
/CAM1_SDA: CON1.14, CON11.12
/CAM2_CLK_N: CON2.8, CON12.8
/CAM2_CLK_P: CON2.7, CON12.7
/CAM2_D0_N: CON2.14, CON12.10
/CAM2_D0_P: CON2.13, CON12.9
/CAM2_D1_N: CON2.11, CON12.6
/CAM2_D1_P: CON2.10, CON12.5
/CAM2_EN: CON2.5, R9.2, U3.1 (B)
/CAM2_LED: CON2.4, TP2.1
/CAM2_SCL: CON2.3, CON12.11
/CAM2_SDA: CON2.2, CON12.12
/EN: R10.1, TP8.1, U1.3 (~SHDN), U2.3 (~SHDN), U3.4 (OUT)
/MCLK: CON11.14, CON12.14, R3.1, TP9.1
GND: C1.2, C2.2, C3.2, C4.2, C5.2, C6.2, C7.2, C8.2, C9.2, C10.2, C11.2, C12.2, C13.2, C14.2, C15.2, C16.2, C17.2, CON1.1, CON1.4, CON1.7, CON1.10, CON2.6, CON2.9, CON2.12, CON2.15, CON11.13, CON11.15, CON11.17, CON12.13, CON12.15, CON12.17, R1.1, R2.1, R4.1, R6.1, R8.1, R9.1, TP4.1, TP6.1, U1.2 (GND), U2.2 (GND), U3.3 (GND), X1.2 (GND)
unnamed: C1.1, C2.1, CON11.18, L1.2
unnamed: C4.1, C5.1, CON11.20, L2.2
unnamed: C6.1, C7.1, CON12.18, L3.2
unnamed: C9.1, C10.1, CON12.20, L4.2
unnamed: CON11.24, R1.2
unnamed: CON12.24, R2.2
unnamed: R3.2, X1.3 (OUT)
unnamed: R4.2, R5.2, U1.4 (NC/FB)
unnamed: R6.2, R7.2, U2.4 (NC/FB)

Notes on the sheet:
Bottom contact
DNP
P5V04A SUNNY
Top contact

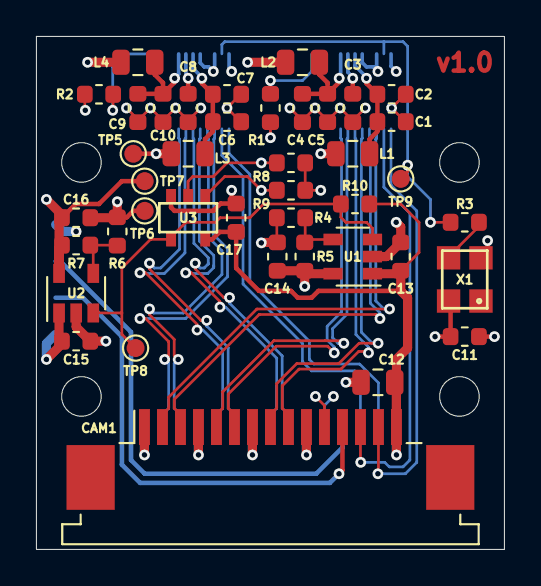
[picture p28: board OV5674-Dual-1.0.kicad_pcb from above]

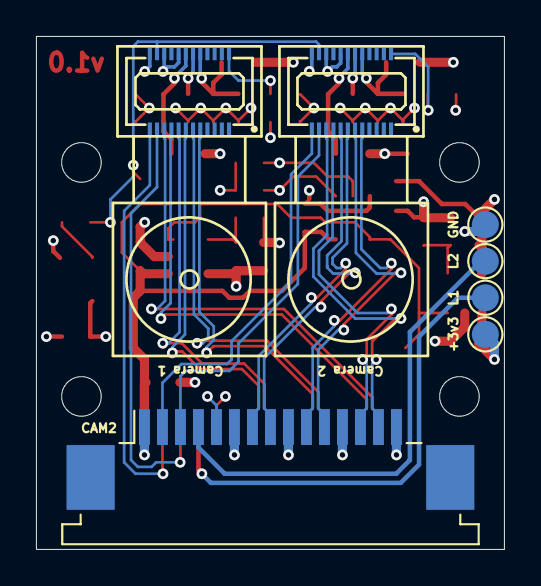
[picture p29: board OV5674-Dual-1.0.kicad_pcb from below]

Board: 4 copper layers, 26.0 x 28.5 mm, 48 parts (7 on the bottom side), 35 nets.

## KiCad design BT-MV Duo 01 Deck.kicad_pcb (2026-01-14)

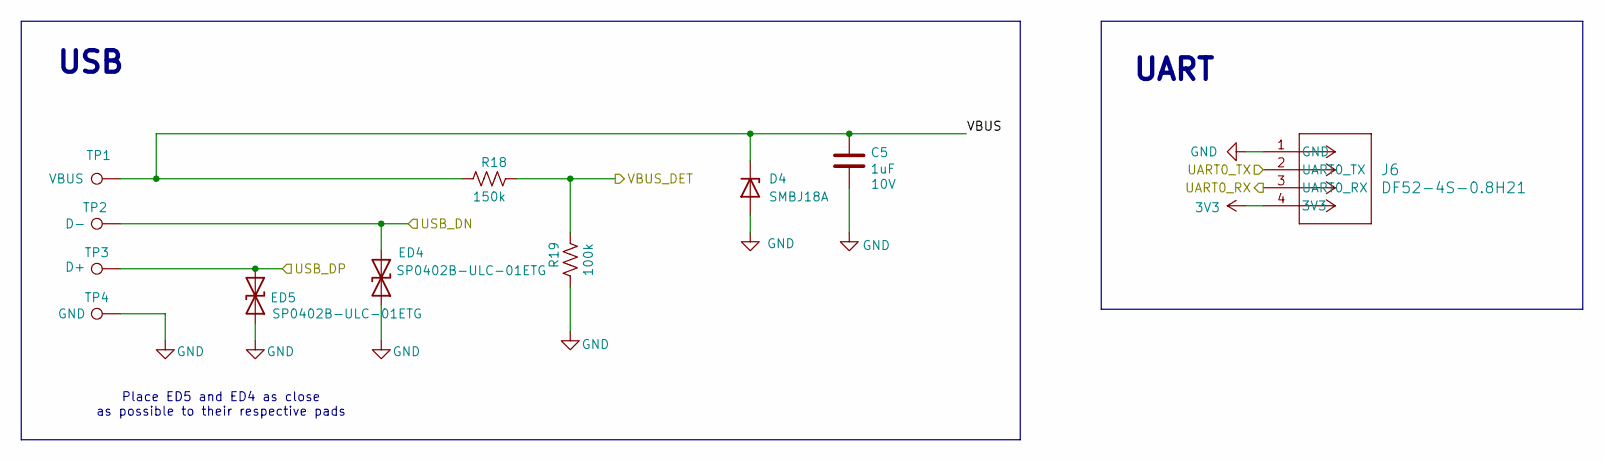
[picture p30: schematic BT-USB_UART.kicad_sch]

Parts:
C5: 1uF; C_0603_1608Metric
D4: SMBJ18A; D_SOD-123F
ED4, ED5: SP0402B-ULC-01ETG; D_0402_1005Metric
J6: DF52-4S-0.8H21; CONN4X1_DF52-4S-0.8H21_HIR
R18: 150k; R_0201_0603Metric_Pad0.64x0.40mm_HandSolder
R19: 100k; R_0201_0603Metric_Pad0.64x0.40mm_HandSolder
TP1: VBUS; TestPoint_Pad_D1.0mm
TP2: D-; TestPoint_Pad_D1.0mm
TP3: D+; TestPoint_Pad_D1.0mm
TP4: GND; TestPoint_Pad_D1.0mm

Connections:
3V3: J6.4 (3V3); also elsewhere on the board
/CF Proto EXP/VBUS: C5.1, D4.1 (K), R18.2, TP1.1; also elsewhere on the board
/Milk Module/UART0_RX: J6.3 (UART0_RX); also elsewhere on the board
/Milk Module/UART0_TX: J6.2 (UART0_TX); also elsewhere on the board
/Milk Module/USB_DN: ED4.2 (A2), TP2.1; also elsewhere on the board
/Milk Module/USB_DP: ED5.2 (A2), TP3.1; also elsewhere on the board
/Milk Module/VBUS_DET: R18.1, R19.1; also elsewhere on the board
GND: C5.2, D4.2 (A), ED4.1 (A1), ED5.1 (A1), J6.1 (GND), R19.2, TP4.1; also elsewhere on the board

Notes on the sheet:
UART
USB
Place ED5 and ED4 as close as possible to their respective pads

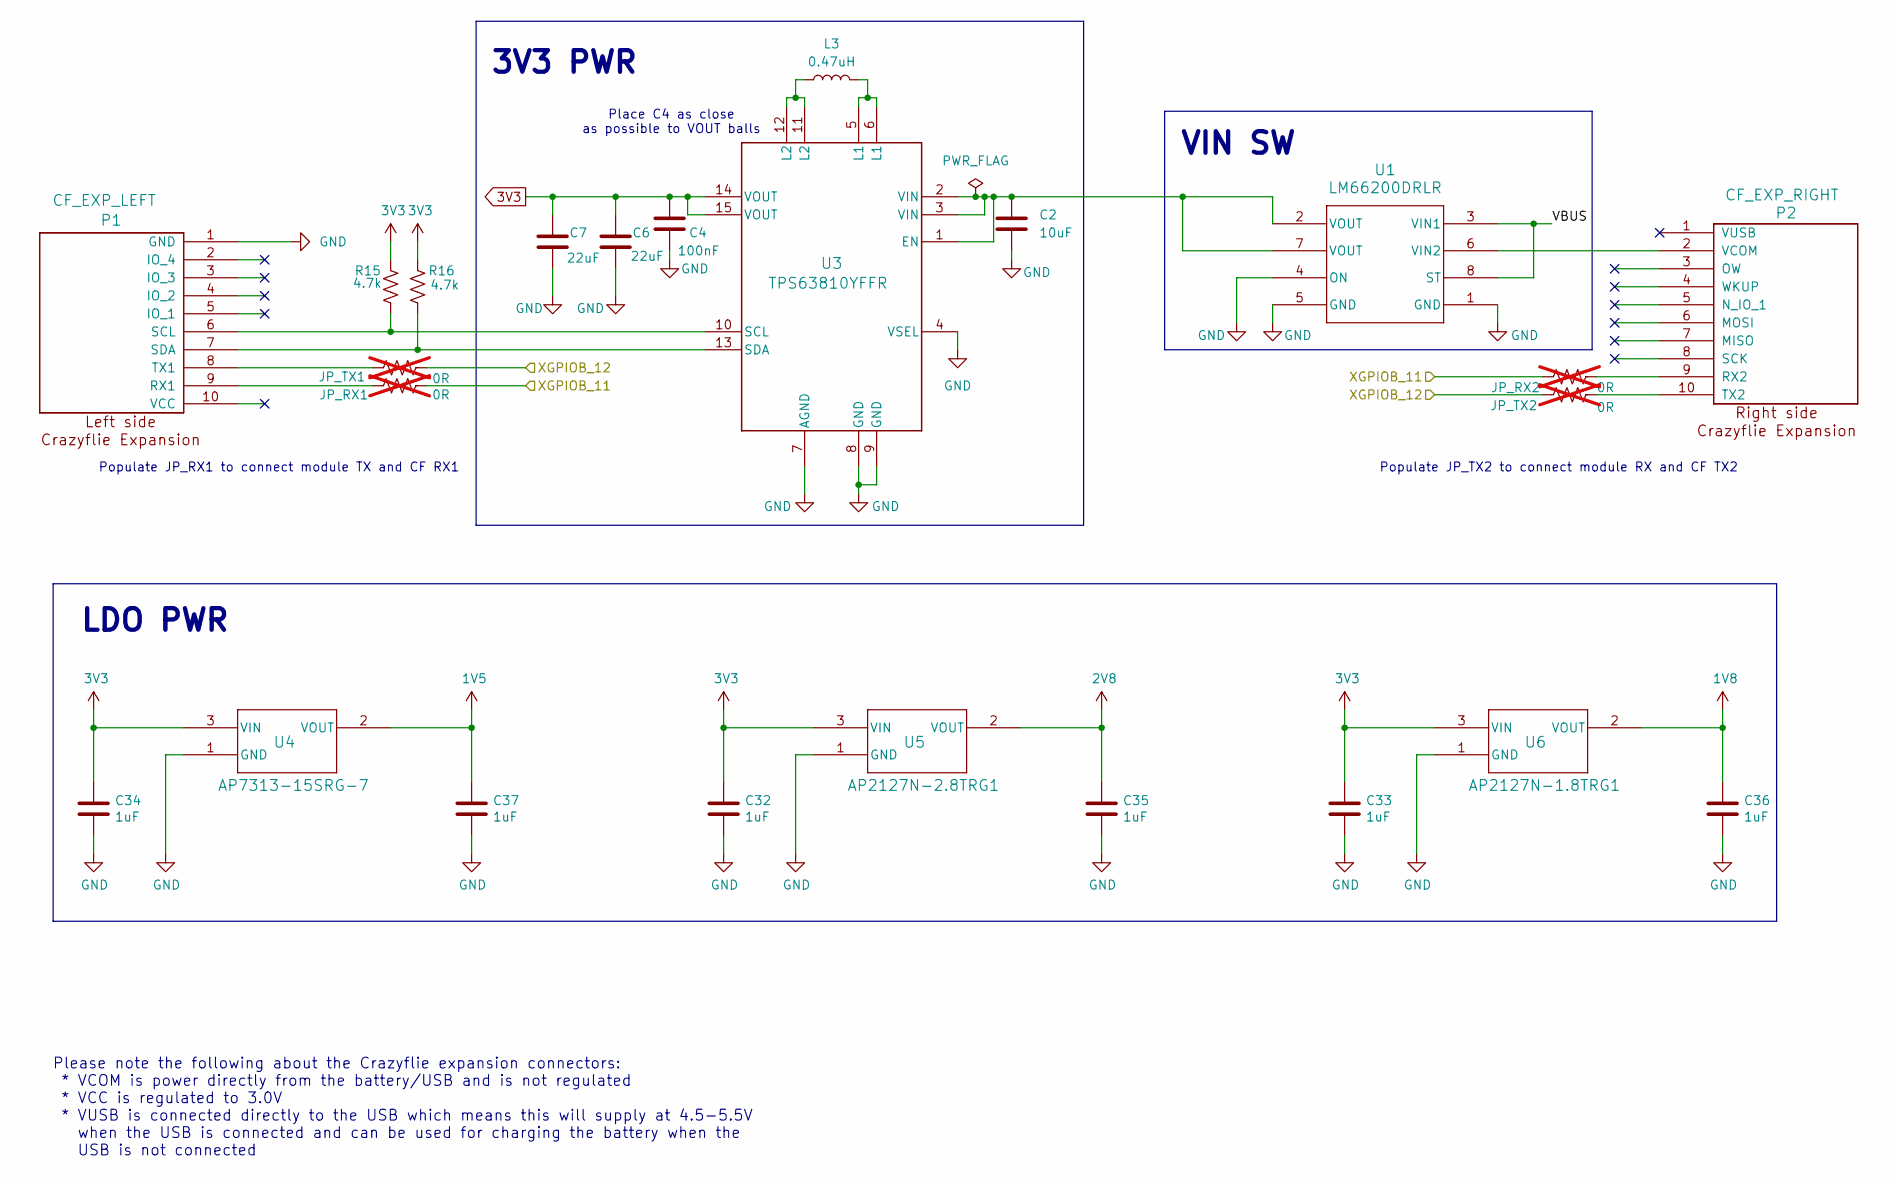
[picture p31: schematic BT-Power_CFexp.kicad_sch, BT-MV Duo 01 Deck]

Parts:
C2: 10uF; C_0201_0603Metric_Pad0.64x0.40mm_HandSolder
C4: 100nF; C_0201_0603Metric_Pad0.64x0.40mm_HandSolder
C6, C7: 22uF; C_0402_1005Metric_Pad0.74x0.62mm_HandSolder
C32, C33, C34, C35, C36, C37: 1uF; C_0603_1608Metric
JP_RX1, JP_RX2: 0R; R_0402_1005Metric; not fitted
JP_TX1, JP_TX2: 0R; R_0402_1005Metric; not fitted
L3: 0.47uH; L_0201_0603Metric_Pad0.64x0.40mm_HandSolder
P1: CF_EXP_LEFT; CF2-DECK-SMD-HOLES
P2: CF_EXP_RIGHT; CF2-DECK-SMD-HOLES
R15, R16: 4.7k; R_0201_0603Metric_Pad0.64x0.40mm_HandSolder
U1: LM66200DRLR; SOT-5X3_DRL_TEX
U3: TPS63810YFFR; YFF0015AHAN
U4: AP7313-15SRG-7; SOT-23_DIO
U5: AP2127N-2.8TRG1; SOT-23_DIO
U6: AP2127N-1.8TRG1; SOT-23_DIO

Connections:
1V5: C37.1, U4.2 (VOUT); also elsewhere on the board
1V8: C36.1, U6.2 (VOUT); also elsewhere on the board
2V8: C35.1, U5.2 (VOUT); also elsewhere on the board
3V3: C4.1, C6.1, C7.1, C32.1, C33.1, C34.1, R15.2, R16.2, U3.14 (VOUT), U3.15 (VOUT), U4.3 (VIN), U5.3 (VIN), U6.3 (VIN); also elsewhere on the board
/CF Proto EXP/VBUS: U1.3 (VIN1), U1.8 (ST); also elsewhere on the board
/Milk Module/XGPIOB_11: JP_RX1.2, JP_RX2.1; also elsewhere on the board
/Milk Module/XGPIOB_12: JP_TX1.2, JP_TX2.1; also elsewhere on the board
GND: C2.2, C4.2, C6.2, C7.2, C32.2, C33.2, C34.2, C35.2, C36.2, C37.2, P1.1 (GND), U1.1 (GND), U1.4 (ON), U1.5 (GND), U3.4 (VSEL), U3.7 (AGND), U3.8 (GND), U3.9 (GND), U4.1 (GND), U5.1 (GND), U6.1 (GND); also elsewhere on the board
unnamed: L3.1, U3.5 (L1), U3.6 (L1)
unnamed: L3.2, U3.11 (L2), U3.12 (L2)
unnamed: JP_RX1.1, P1.9 (RX1)
unnamed: P1.6 (SCL), R15.1, U3.10 (SCL)
unnamed: P1.7 (SDA), R16.1, U3.13 (SDA)
unnamed: JP_TX1.1, P1.8 (TX1)
unnamed: JP_RX2.2, P2.9 (RX2)
unnamed: JP_TX2.2, P2.10 (TX2)
unnamed: P2.2 (VCOM), U1.6 (VIN2)
unnamed: C2.1, U1.2 (VOUT), U1.7 (VOUT), U3.1 (EN), U3.2 (VIN), U3.3 (VIN)

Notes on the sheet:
Populate JP_TX2 to connect module RX and CF TX2
Please note the following about the Crazyflie expansion connectors: * VCOM is power directly from the battery/USB and is not regulated * VCC is regulated to 3.0V * VUSB is connected directly to the USB which means this will supply at 4.5-5.5V when the USB is connected and can be used for charging t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
LDO PWR
3V3 PWR
Populate JP_RX1 to connect module TX and CF RX1
VIN SW
Place C4 as close as possible to VOUT balls

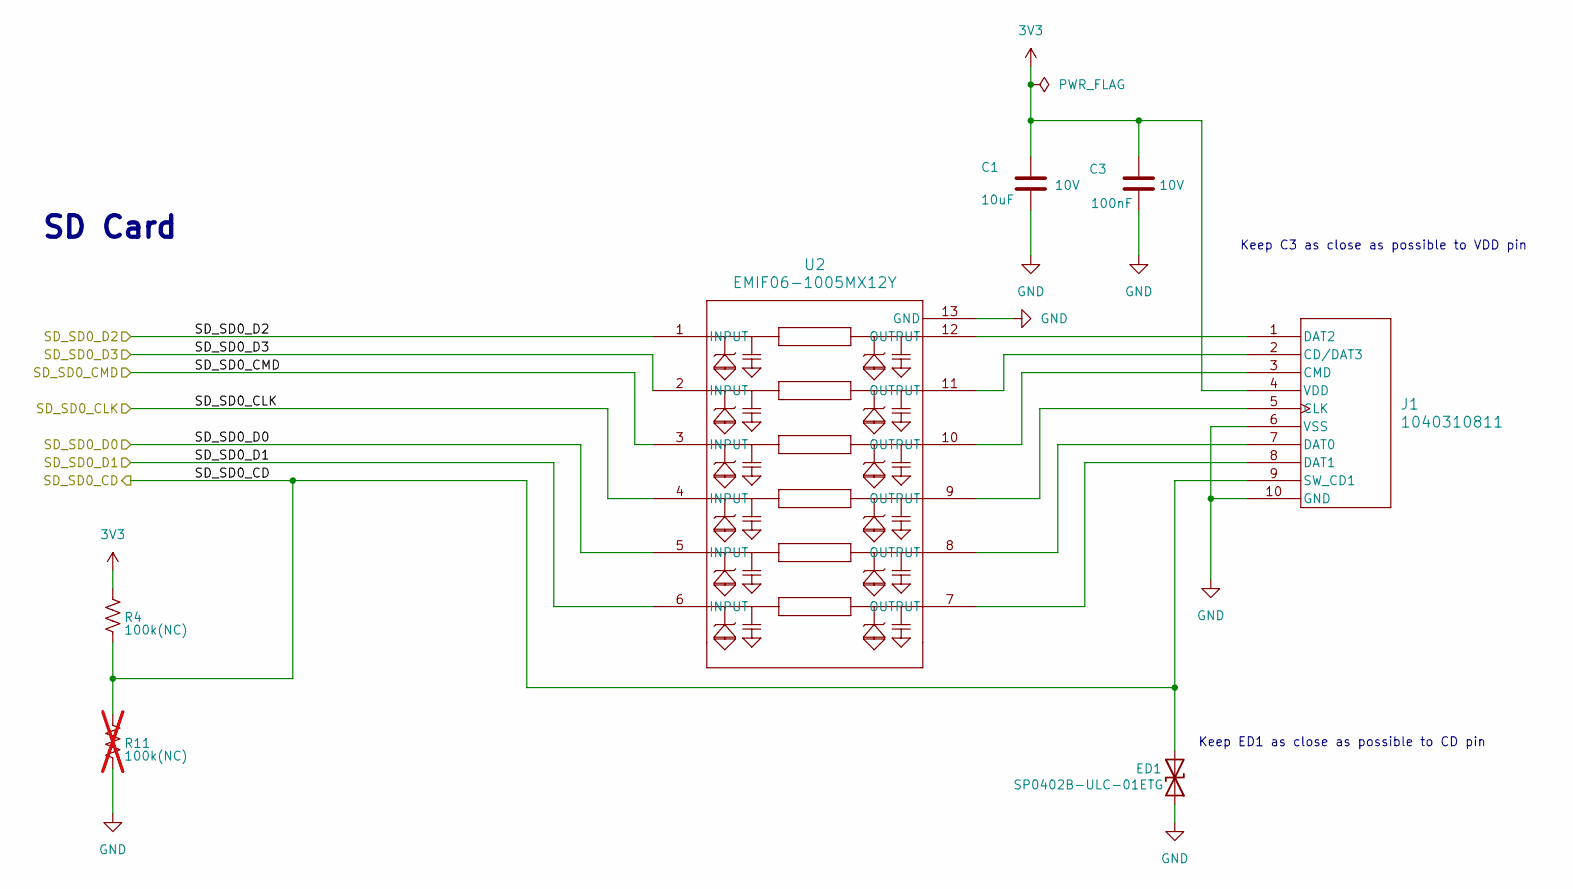
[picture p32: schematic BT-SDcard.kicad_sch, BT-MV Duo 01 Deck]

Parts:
C1: 10uF; C_0603_1608Metric_Pad1.08x0.95mm_HandSolder; VOLTAGE 10V; TOLERANCE 10%
C3: 100nF; C_0402_1005Metric_Pad0.74x0.62mm_HandSolder; VOLTAGE 10V; TOLERANCE 10%
ED1: SP0402B-ULC-01ETG; D_0402_1005Metric
J1: 1040310811; 104031-0811_MOL
R4: 100k(NC); R_0402_1005Metric_Pad0.72x0.64mm_HandSolder
R11: 100k(NC); R_0402_1005Metric_Pad0.72x0.64mm_HandSolder; not fitted
U2: EMIF06-1005MX12Y; SON_5MX12Y_STM

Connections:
3V3: C1.1, C3.1, J1.4 (VDD), R4.1; also elsewhere on the board
/Milk Module/SD_SD0_CD: ED1.2 (A2), J1.9 (SW_CD1), R4.2, R11.1; also elsewhere on the board
/Milk Module/SD_SD0_CLK: U2.4 (INPUT); also elsewhere on the board
/Milk Module/SD_SD0_CMD: U2.3 (INPUT); also elsewhere on the board
/Milk Module/SD_SD0_D0: U2.5 (INPUT); also elsewhere on the board
/Milk Module/SD_SD0_D1: U2.6 (INPUT); also elsewhere on the board
/Milk Module/SD_SD0_D2: U2.1 (INPUT); also elsewhere on the board
/Milk Module/SD_SD0_D3: U2.2 (INPUT); also elsewhere on the board
GND: C1.2, C3.2, ED1.1 (A1), J1.6 (VSS), J1.10 (GND), R11.2, U2.13 (GND); also elsewhere on the board
unnamed: J1.2 (CD/DAT3), U2.11 (OUTPUT)
unnamed: J1.5 (CLK), U2.9 (OUTPUT)
unnamed: J1.3 (CMD), U2.10 (OUTPUT)
unnamed: J1.7 (DAT0), U2.8 (OUTPUT)
unnamed: J1.8 (DAT1), U2.7 (OUTPUT)
unnamed: J1.1 (DAT2), U2.12 (OUTPUT)

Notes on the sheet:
Keep ED1 as close as possible to CD pin
SD Card
Keep C3 as close as possible to VDD pin

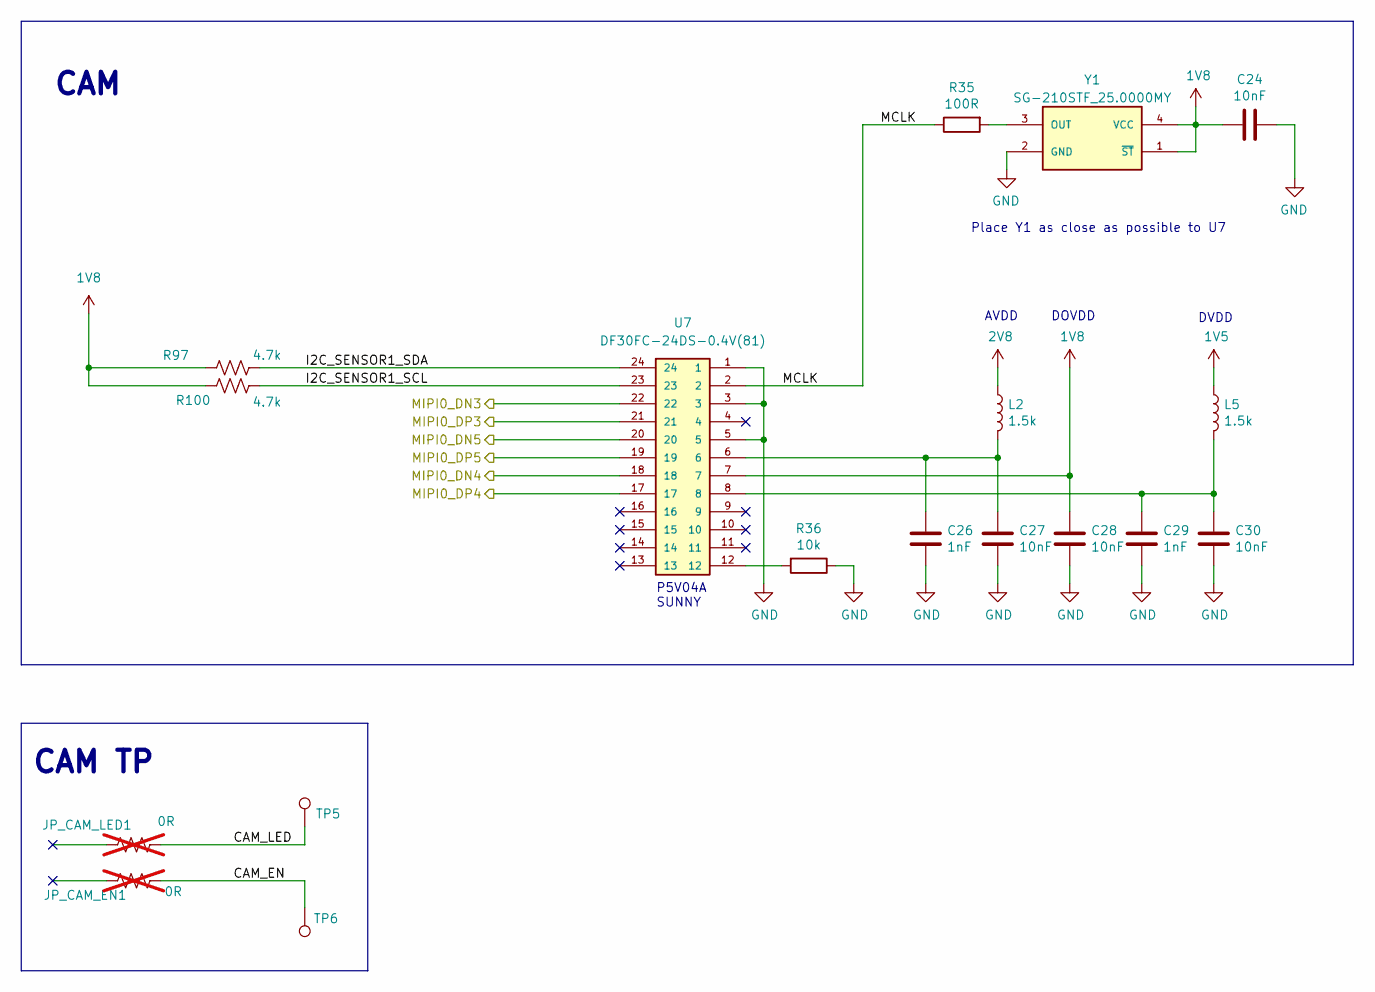
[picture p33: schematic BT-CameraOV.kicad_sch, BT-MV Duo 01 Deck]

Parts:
C24, C27, C28, C30: 10nF; C_0603_1608Metric
C26, C29: 1nF; C_0603_1608Metric
JP_CAM_EN1: 0R; R_0402_1005Metric; not fitted
JP_CAM_LED1: 0R; R_0402_1005Metric; not fitted
L2, L5: 1.5k; L_0805_2012Metric
R35: 100R; R_0603_1608Metric
R36: 10k; R_0603_1608Metric
R97, R100: 4.7k; R_0201_0603Metric_Pad0.64x0.40mm_HandSolder
TP5, TP6: TestPoint; TestPoint_Pad_D1.0mm
U7: DF30FC-24DS-0.4V(81); DF30FC-24DS
Y1: SG-210STF_25.0000MY; OSCCC250X200X90

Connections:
1V5: L5.1; also elsewhere on the board
1V8: C24.1, C28.1, R97.1, R100.1, U7.7, Y1.1 (~ST), Y1.4 (VCC); also elsewhere on the board
2V8: L2.1; also elsewhere on the board
/Camera OV/CAM_EN: JP_CAM_EN1.2, TP6.1
/Camera OV/CAM_LED: JP_CAM_LED1.2, TP5.1
/Camera OV/I2C_SENSOR1_SCL: R100.2, U7.23
/Camera OV/I2C_SENSOR1_SDA: R97.2, U7.24
/Camera OV/MCLK: R35.1, U7.2
/Milk Module/MIPI0_DN3: U7.22; also elsewhere on the board
/Milk Module/MIPI0_DN4: U7.18; also elsewhere on the board
/Milk Module/MIPI0_DN5: U7.20; also elsewhere on the board
/Milk Module/MIPI0_DP3: U7.21; also elsewhere on the board
/Milk Module/MIPI0_DP4: U7.17; also elsewhere on the board
/Milk Module/MIPI0_DP5: U7.19; also elsewhere on the board
GND: C24.2, C26.2, C27.2, C28.2, C29.2, C30.2, R36.1, U7.1, U7.3, U7.5, Y1.2 (GND); also elsewhere on the board
unnamed: C26.1, C27.1, L2.2, U7.6
unnamed: C29.1, C30.1, L5.2, U7.8
unnamed: R36.2, U7.12
unnamed: R35.2, Y1.3 (OUT)

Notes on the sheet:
DOVDD
CAM TP
DVDD
Place Y1 as close as possible to U7
CAM
P5V04A SUNNY
AVDD

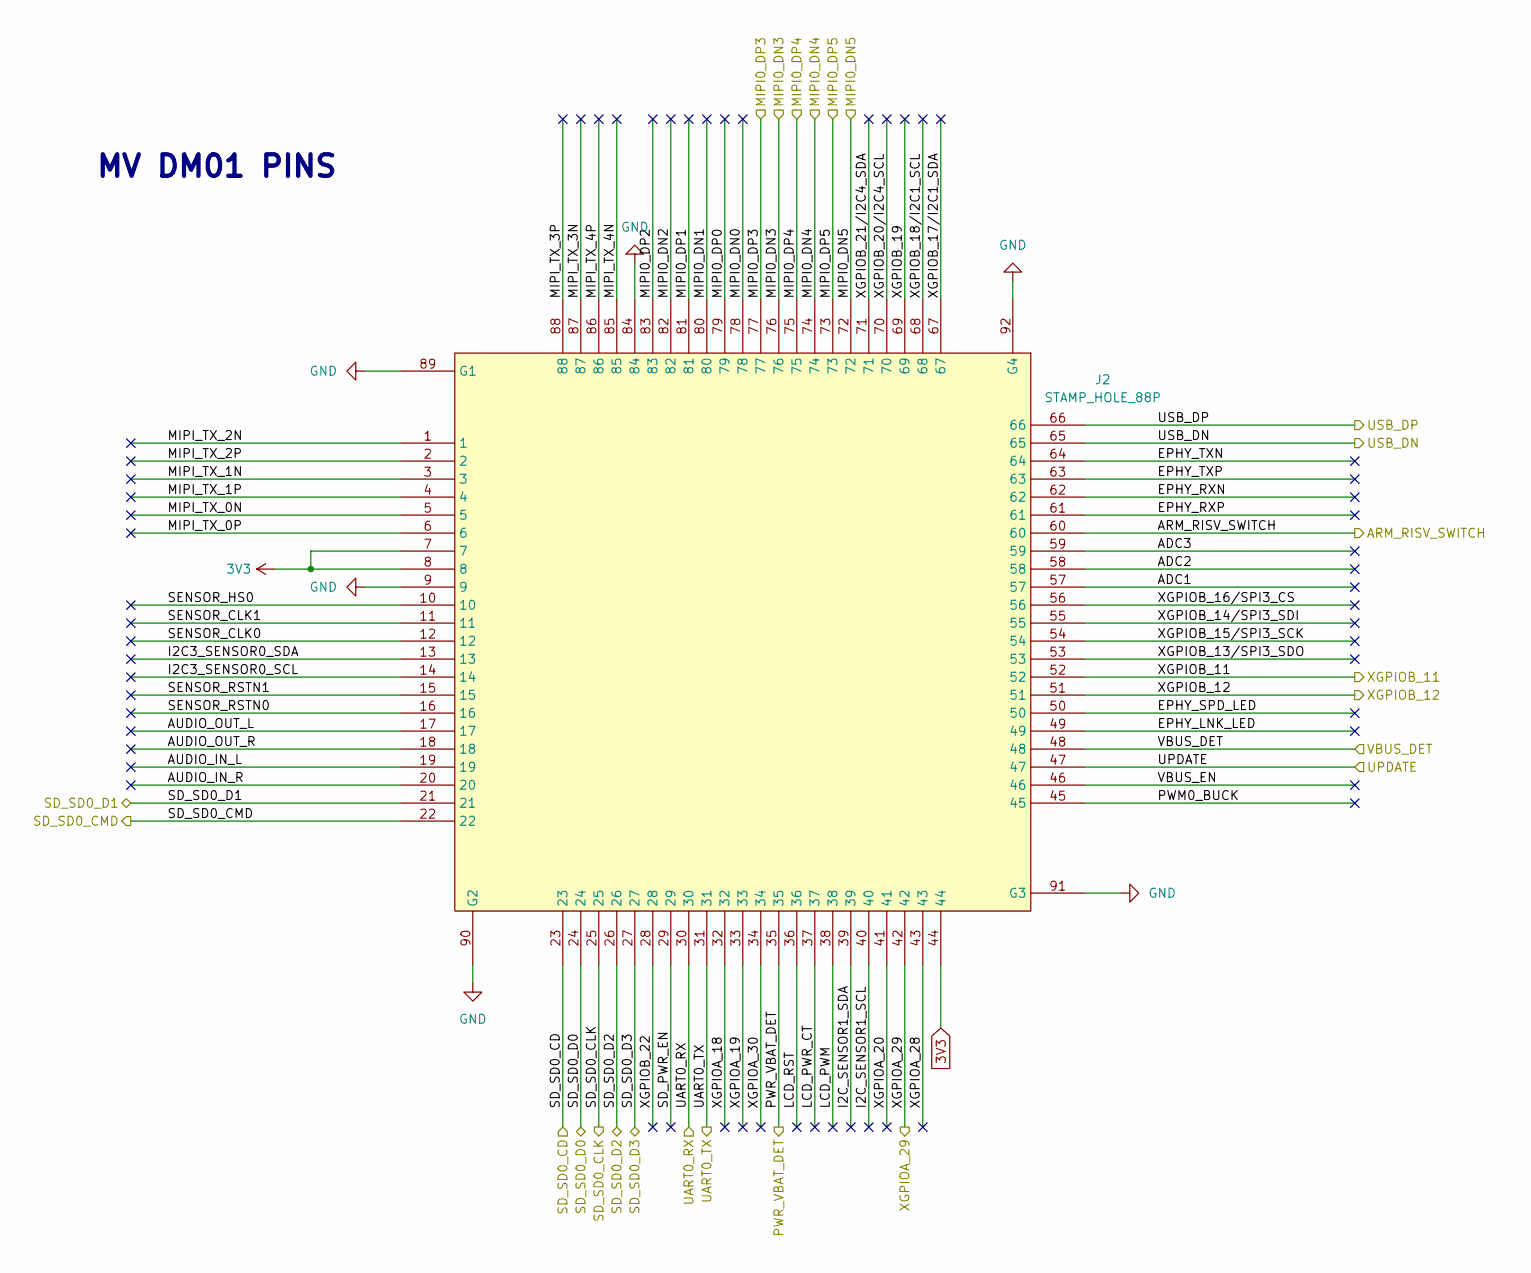
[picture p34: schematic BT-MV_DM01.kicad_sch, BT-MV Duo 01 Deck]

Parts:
J2: STAMP_HOLE_88P; MilkV_Duo_Module

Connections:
3V3: J2.7, J2.8, J2.44; also elsewhere on the board
/Milk Module/ADC1: J2.57
/Milk Module/ADC2: J2.58
/Milk Module/ADC3: J2.59
/Milk Module/ARM_RISV_SWITCH: J2.60; also elsewhere on the board
/Milk Module/AUDIO_IN_L: J2.19
/Milk Module/AUDIO_IN_R: J2.20
/Milk Module/AUDIO_OUT_L: J2.17
/Milk Module/AUDIO_OUT_R: J2.18
/Milk Module/EPHY_LNK_LED: J2.49
/Milk Module/EPHY_RXN: J2.62
/Milk Module/EPHY_RXP: J2.61
/Milk Module/EPHY_SPD_LED: J2.50
/Milk Module/EPHY_TXN: J2.64
/Milk Module/EPHY_TXP: J2.63
/Milk Module/I2C3_SENSOR0_SCL: J2.14
/Milk Module/I2C3_SENSOR0_SDA: J2.13
/Milk Module/I2C_SENSOR1_SCL: J2.40
/Milk Module/I2C_SENSOR1_SDA: J2.39
/Milk Module/LCD_PWM: J2.38
/Milk Module/LCD_PWR_CT: J2.37
/Milk Module/LCD_RST: J2.36
/Milk Module/MIPI0_DN0: J2.78
/Milk Module/MIPI0_DN1: J2.80
/Milk Module/MIPI0_DN2: J2.82
/Milk Module/MIPI0_DN3: J2.76; also elsewhere on the board
/Milk Module/MIPI0_DN4: J2.74; also elsewhere on the board
/Milk Module/MIPI0_DN5: J2.72; also elsewhere on the board
/Milk Module/MIPI0_DP0: J2.79
/Milk Module/MIPI0_DP1: J2.81
/Milk Module/MIPI0_DP2: J2.83
/Milk Module/MIPI0_DP3: J2.77; also elsewhere on the board
/Milk Module/MIPI0_DP4: J2.75; also elsewhere on the board
/Milk Module/MIPI0_DP5: J2.73; also elsewhere on the board
/Milk Module/MIPI_TX_0N: J2.5
/Milk Module/MIPI_TX_0P: J2.6
/Milk Module/MIPI_TX_1N: J2.3
/Milk Module/MIPI_TX_1P: J2.4
/Milk Module/MIPI_TX_2N: J2.1
/Milk Module/MIPI_TX_2P: J2.2
/Milk Module/MIPI_TX_3N: J2.87
/Milk Module/MIPI_TX_3P: J2.88
/Milk Module/MIPI_TX_4N: J2.85
/Milk Module/MIPI_TX_4P: J2.86
/Milk Module/PWM0_BUCK: J2.45
/Milk Module/PWR_VBAT_DET: J2.35; also elsewhere on the board
/Milk Module/SD_PWR_EN: J2.29
/Milk Module/SD_SD0_CD: J2.23; also elsewhere on the board
/Milk Module/SD_SD0_CLK: J2.25; also elsewhere on the board
/Milk Module/SD_SD0_CMD: J2.22; also elsewhere on the board
/Milk Module/SD_SD0_D0: J2.24; also elsewhere on the board
/Milk Module/SD_SD0_D1: J2.21; also elsewhere on the board
/Milk Module/SD_SD0_D2: J2.26; also elsewhere on the board
/Milk Module/SD_SD0_D3: J2.27; also elsewhere on the board
/Milk Module/SENSOR_CLK0: J2.12
/Milk Module/SENSOR_CLK1: J2.11
/Milk Module/SENSOR_HS0: J2.10
/Milk Module/SENSOR_RSTN0: J2.16
/Milk Module/SENSOR_RSTN1: J2.15
/Milk Module/UART0_RX: J2.30; also elsewhere on the board
/Milk Module/UART0_TX: J2.31; also elsewhere on the board
/Milk Module/UPDATE: J2.47; also elsewhere on the board
/Milk Module/USB_DN: J2.65; also elsewhere on the board
/Milk Module/USB_DP: J2.66; also elsewhere on the board
/Milk Module/VBUS_DET: J2.48; also elsewhere on the board
/Milk Module/VBUS_EN: J2.46
/Milk Module/XGPIOA_18: J2.32
/Milk Module/XGPIOA_19: J2.33
/Milk Module/XGPIOA_20: J2.41
/Milk Module/XGPIOA_28: J2.43
/Milk Module/XGPIOA_29: J2.42; also elsewhere on the board
/Milk Module/XGPIOA_30: J2.34
/Milk Module/XGPIOB_11: J2.52; also elsewhere on the board
/Milk Module/XGPIOB_12: J2.51; also elsewhere on the board
/Milk Module/XGPIOB_13/SPI3_SDO: J2.53
/Milk Module/XGPIOB_14/SPI3_SDI: J2.55
/Milk Module/XGPIOB_15/SPI3_SCK: J2.54
/Milk Module/XGPIOB_16/SPI3_CS: J2.56
/Milk Module/XGPIOB_17/I2C1_SDA: J2.67
/Milk Module/XGPIOB_18/I2C1_SCL: J2.68
/Milk Module/XGPIOB_19: J2.69
/Milk Module/XGPIOB_20/I2C4_SCL: J2.70
/Milk Module/XGPIOB_21/I2C4_SDA: J2.71
/Milk Module/XGPIOB_22: J2.28
GND: J2.9, J2.84, J2.89 (G1), J2.90 (G2), J2.91 (G3), J2.92 (G4); also elsewhere on the board

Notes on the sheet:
MV DM01 PINS

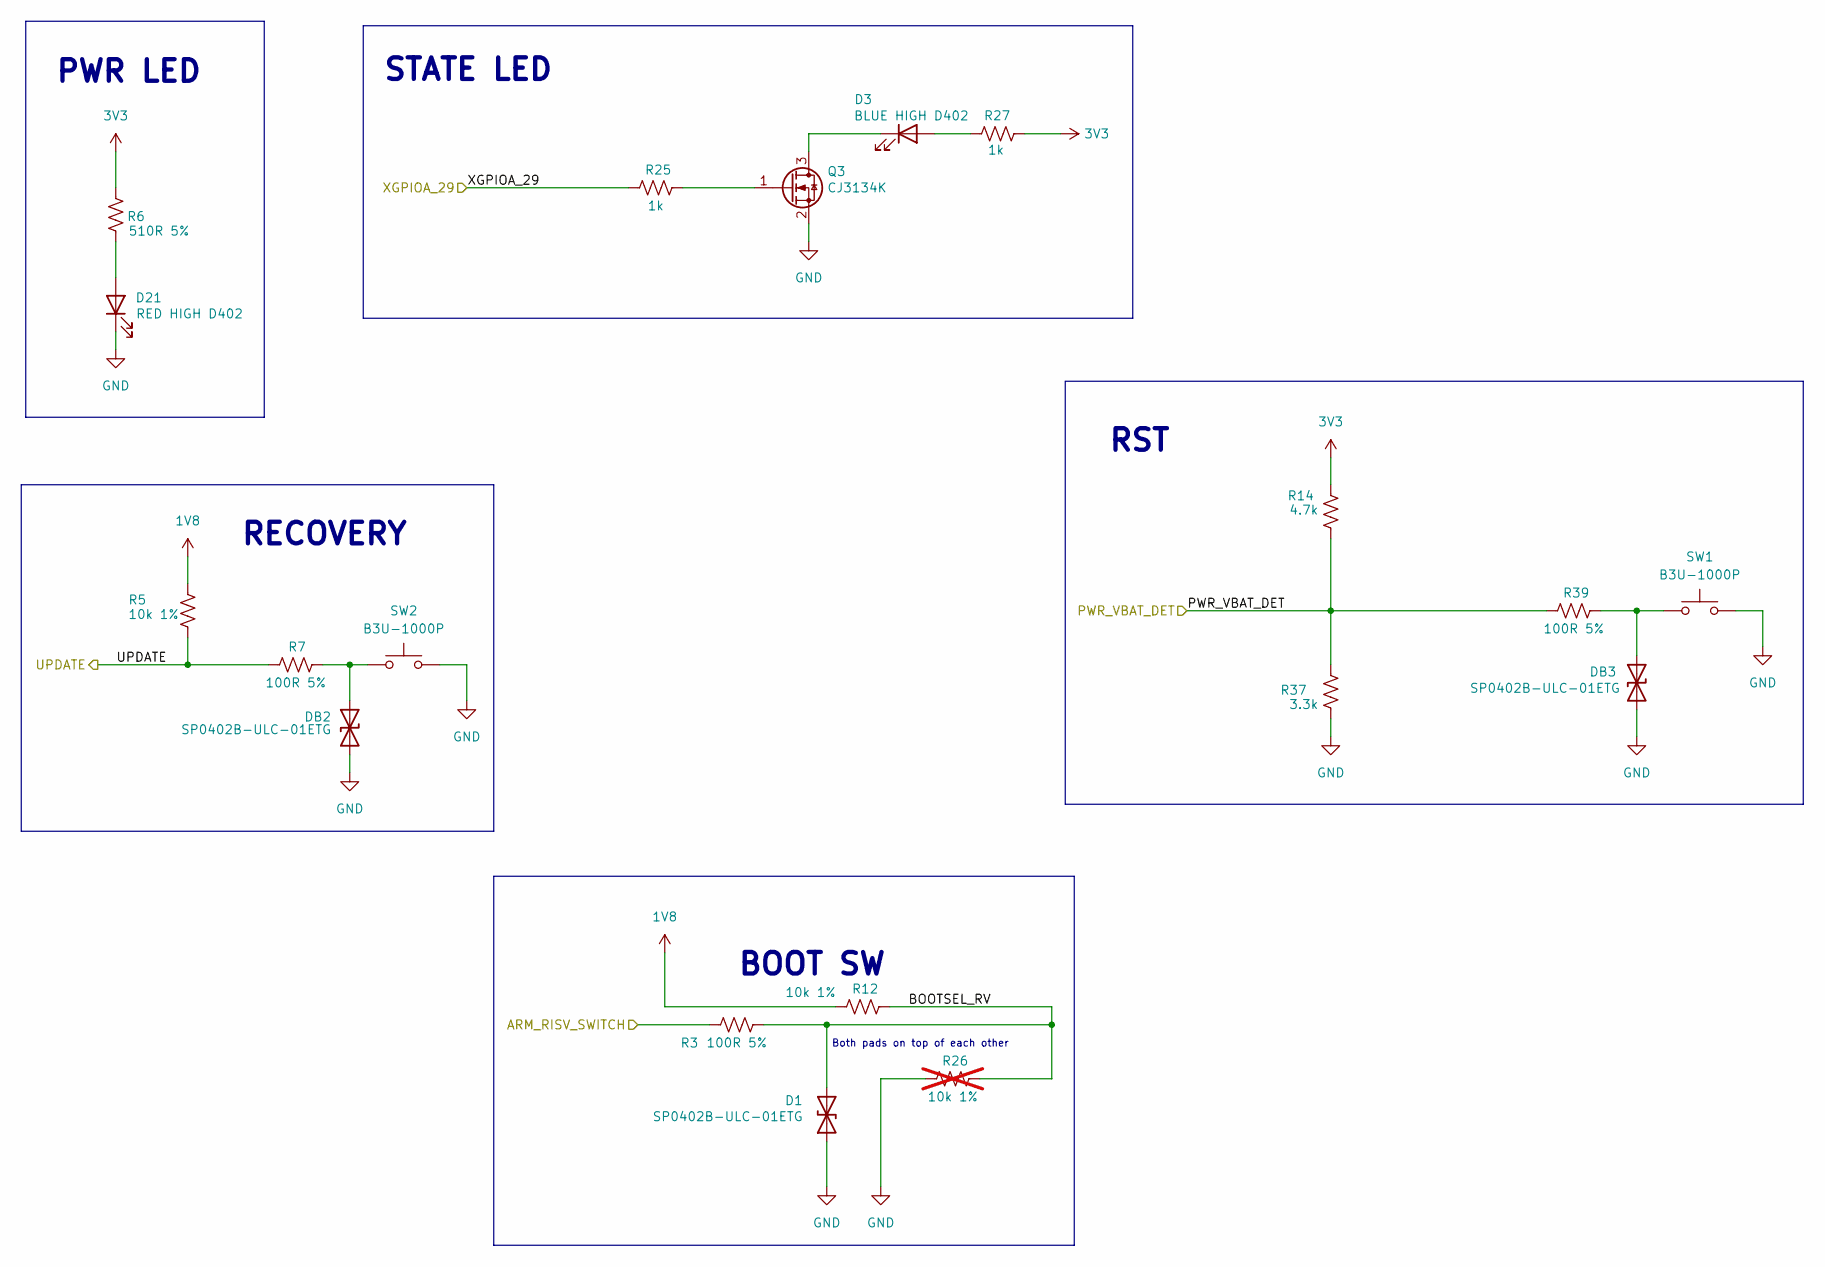
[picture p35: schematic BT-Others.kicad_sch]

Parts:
D1: SP0402B-ULC-01ETG; D_0402_1005Metric
D3: BLUE HIGH D402; LED_0402_1005Metric_Pad0.77x0.64mm_HandSolder
D21: RED HIGH D402; LED_0402_1005Metric_Pad0.77x0.64mm_HandSolder
DB2, DB3: SP0402B-ULC-01ETG; D_0402_1005Metric
Q3: CJ3134K; SOT-723
R3, R7, R39: 100R 5%; R_0201_0603Metric_Pad0.64x0.40mm_HandSolder
R5, R12: 10k 1%; R_0201_0603Metric_Pad0.64x0.40mm_HandSolder
R6: 510R 5%; R_0402_1005Metric_Pad0.72x0.64mm_HandSolder
R14: 4.7k; R_0201_0603Metric_Pad0.64x0.40mm_HandSolder
R25, R27: 1k; R_0402_1005Metric_Pad0.72x0.64mm_HandSolder
R26: 10k 1%; R_0201_0603Metric_Pad0.64x0.40mm_HandSolder; not fitted
R37: 3.3k; R_0201_0603Metric_Pad0.64x0.40mm_HandSolder
SW1, SW2: B3U-1000P; SW_SPST_B3U-1000P

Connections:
1V8: R5.1, R12.1; also elsewhere on the board
3V3: R6.1, R14.2, R27.1; also elsewhere on the board
/Milk Module/ARM_RISV_SWITCH: R3.1; also elsewhere on the board
/Milk Module/PWR_VBAT_DET: R14.1, R37.2, R39.1; also elsewhere on the board
/Milk Module/UPDATE: R5.2, R7.1; also elsewhere on the board
/Milk Module/XGPIOA_29: R25.1; also elsewhere on the board
/SD Card/BOOTSEL_RV: D1.2 (A2), R3.2, R12.2, R26.2
GND: D1.1 (A1), D21.1 (K), DB2.2 (A2), DB3.2 (A2), Q3.2 (S), R26.1, R37.1, SW1.2, SW2.2; also elsewhere on the board
unnamed: D3.2 (A), R27.2
unnamed: D3.1 (K), Q3.3 (D)
unnamed: D21.2 (A), R6.2
unnamed: DB2.1 (A1), R7.2, SW2.1
unnamed: DB3.1 (A1), R39.2, SW1.1
unnamed: Q3.1 (G), R25.2

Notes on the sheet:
RST
BOOT SW
Both pads on top of each other
STATE LED
RECOVERY
PWR LED

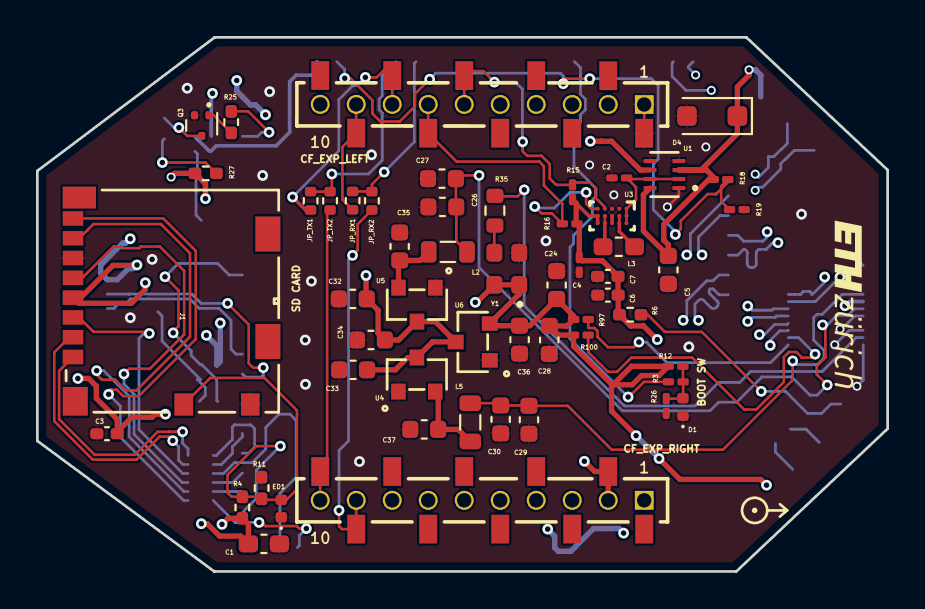
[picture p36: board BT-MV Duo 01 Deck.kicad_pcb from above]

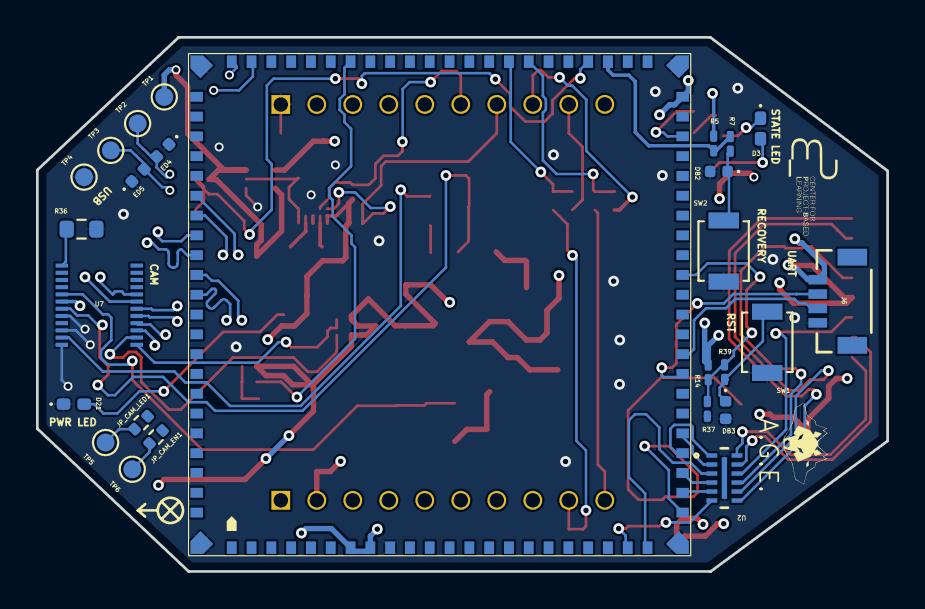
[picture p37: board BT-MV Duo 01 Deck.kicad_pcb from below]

Board: 4 copper layers, 47.2 x 29.7 mm, 81 parts (26 on the bottom side), 62 nets.

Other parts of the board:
EXP_ORIENTATION: VAL**; EXP_ORIENTATION

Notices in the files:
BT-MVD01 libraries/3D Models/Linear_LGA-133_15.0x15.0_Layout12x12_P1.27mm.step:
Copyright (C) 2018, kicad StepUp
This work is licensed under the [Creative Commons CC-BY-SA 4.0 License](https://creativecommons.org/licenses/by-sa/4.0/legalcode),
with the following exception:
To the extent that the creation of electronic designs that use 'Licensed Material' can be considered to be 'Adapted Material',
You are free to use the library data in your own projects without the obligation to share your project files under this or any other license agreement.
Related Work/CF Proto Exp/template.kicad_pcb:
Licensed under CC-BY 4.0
